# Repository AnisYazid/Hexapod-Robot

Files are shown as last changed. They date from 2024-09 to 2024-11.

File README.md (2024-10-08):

# Hexapod Robot with ESP32 and Jetson Nano

<div align="center">

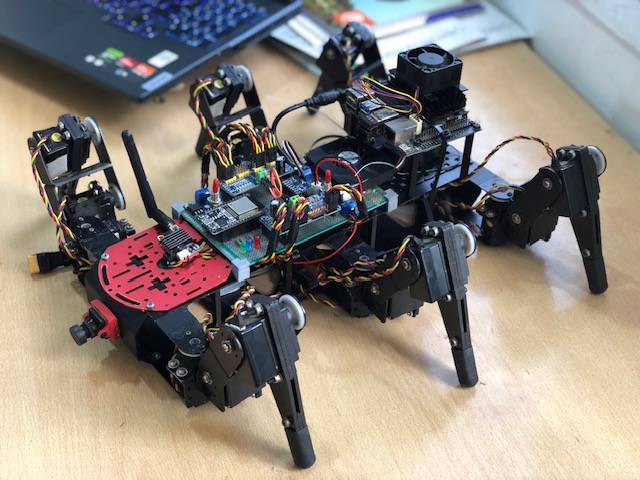
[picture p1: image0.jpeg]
Hexapod Robot
 
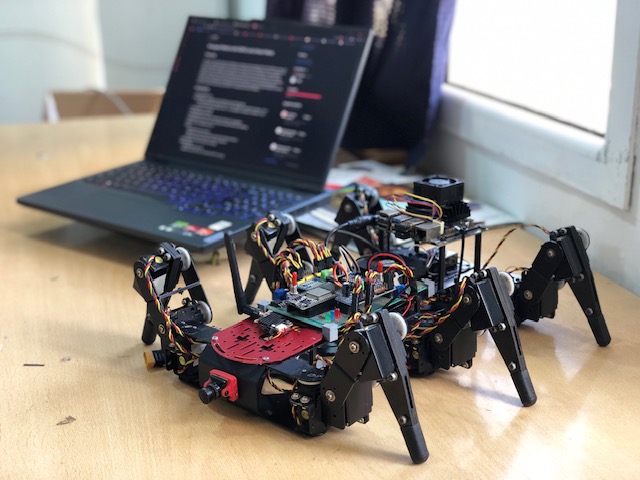
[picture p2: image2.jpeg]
HExapod Robot
 
 
</div>

## Overview
This project involves the design and development of a hexapod robot equipped with 18 HS-475HB servo motors for movement, controlled by an ESP32 microcontroller. The robot utilizes two PCA9685 servo drivers to manage the 18 servos—dividing them between the left and right sides for better control and coordination. An accelerometer is integrated for real-time calibration and stabilization. For movement, the robot employs Algebric Equations for smooth trajectory planning and PID (Proportional-Integral-Derivative) control for precise servo positioning. For autonomous navigation, the robot leverages a Jetson Nano paired with an Xbox Kinect V1 Depth Camera for environmental mapping and obstacle avoidance. Additionally, the robot features a buzzer and LEDs for debugging and status indication. The robot can also be controlled remotely using a Radiolink AT10 transmitter and RD12DS receiver.

## Components
- **Microcontroller:** ESP32
- **Servo Drivers:** 2 x PCA9685 (one for the left side, one for the right side)
  - **Right PCA9685 Address Modification: 0x41 ** A0 pin soldered to change the I2C address ( E-D-F )
  - **Left  PCA9685 Address Modification: 0x42 ** A1 pin soldered to change the I2C address ( A-B-C )
- **Servo Motors:** 18 x HS-475HB
- **Orientation Sensor:** MPU6050 
- **Processing Unit:** Jetson Nano (for advanced processing and AI capabilities)
- **Depth Sensor:** Xbox Kinect V1 (for 3D mapping and object detection amd mapping)
- **Buzzer:** For audio feedback and alerts
- **LEDs:**
  - **Red LED:** Main power indicator
  - **Blue LED:** Connection status indicator (searching for remote and Jetson)
  - **Green LED:** Setup ready indicator (all systems operational)
- **Power Supply:** 12V 30A power Supply 
- **Remote Control:**
  - **Transmitter:** Radiolink AT10II
  - **Receiver:** Radiolink RD12DS (connected to ESP32 via TX2 pin)

## Servo Motor Specification: HS-475HB
- **Modulation:** Analog
- **Torque:**
  - 4.8V: 61.0 oz-in (4.39 kg-cm)
  - 6.0V: 76.0 oz-in (5.47 kg-cm)
- **Speed:**
  - 4.8V: 0.23 sec/60°
  - 6.0V: 0.18 sec/60°
- **Weight:** 1.41 oz (40.0 g)
- **Dimensions:**
  - Length: 1.52 in (38.6 mm)
  - Width: 0.77 in (19.6 mm)
  - Height: 1.41 in (35.8 mm)
- **Motor Type:** 3-pole
- **Gear Type:** Plastic
- **Rotation/Support:** Single Bearing
- **Rotational Range:** 200°
- **Pulse Cycle:** 20 ms
- **Pulse Width:** 900-2100 µs

## Features
- **Dual PCA9685 Control:** Two PCA9685 drivers allow for precise control of 18 HS-475HB servos, with separate management for the left and right sides of the hexapod.

- **Smooth Movement:** Utilizes Bézier curves to generate smooth trajectories for the hexapod's movements, enhancing agility and fluidity.

- **PID Control:** Implements PID control for precise servo positioning, allowing for accurate and stable movement adjustments.
  
- **Real-Time Calibration:** Uses MPU6050 for detecting orientation and adjusting the robot's posture on-the-fly.
  
- **Autonomous Navigation:** Implements SLAM (Simultaneous Localization and Mapping) algorithms for navigating complex environments.
  
- **Obstacle Detection:** Utilizes Kinect V1 for depth perception and real-time obstacle avoidance.
  
- **Debugging Tools:** Buzzer for alerts and LEDs for indicating status (e.g., errors, operational states).
  
- **Remote Control Mode:** Allows manual operation via Radiolink AT10 transmitter.

## Installation
### Prerequisites
- **Hardware:**

  - ESP32 development board
  - 2 x PCA9685 servo drivers
  - 18 x HS-475HB servo motors
  - MPU6050 sensor
  - Jetson Nano
  - Kinect V2 sensor
  - Buzzer
  - LEDs:
    - Red for power
    - Blue for connection status
    - Green for setup readiness
  - Resistors for LEDs (if needed)
  - Radiolink AT10 transmitter
  - Radiolink RD12DS receiver
  - Power supply 12V 30A 
 
- **Software:**

   ```bash
   git clone https://github.com/yourusername/hexapod-robot.git
   cd hexapod-robot
   
### Install ESP32 Libraries
1. Open the Arduino IDE.
2. Go to **Sketch > Include Library > Manage Libraries**.
3. Search for and install:
   - Adafruit PWM Servo Driver Library
   - MPU6050 library
   - PID library (if necessary for your implementation)

### Install Jetson Nano Libraries
1. Open a terminal and install OpenCV:
   ```bash
   sudo apt-get install python3-opencv
   
2. Install ROS (Robot Operating System) following: [official ROS installation instructions](http://wiki.ros.org/ROS/Installation).
   
## Pinout

### ESP32 Connections
- **PCA9685 Servo Driver 1:**
  - SDA: GPIO 21
  - SCL: GPIO 22
  - **Servos:**
    - Servo A1: Channel 2
    - Servo A2: Channel 1
    - Servo A3: Channel 0
    - Servo B1: Channel 6
    - Servo B2: Channel 5
    - Servo B3: Channel 4
    - Servo C1: Channel 15
    - Servo C2: Channel 14
    - Servo C3: Channel 13

- **PCA9685 Servo Driver 2:**
  - SDA: GPIO 21
  - SCL: GPIO 22
  - **Servos:**
    - Servo D1: Channel 15
    - Servo D2: Channel 14
    - Servo D3: Channel 13
    - Servo E1: Channel 6
    - Servo E2: Channel 5
    - Servo E3: Channel 4
    - Servo F1: Channel 2
    - Servo F2: Channel 1
    - Servo F3: Channel 0
- **MPU6050:**
  - SDA: GPIO 21
  - SCL: GPIO 22
  - (Note: The MPU6050 also shares the same I2C pins)

- **LEDs:**
  - Red LED: GPIO 25
  - Blue LED: GPIO 4
  - Green LED: GPIO 2

- **Buzzer:**
  - Buzzer: GPIO 26
 
## Troubleshooting
### Common Issues

#### Servo Not Responding:
- Check the power supply to ensure the servos are receiving adequate voltage.
- Verify the wiring connections to the PCA9685 and ESP32.
- Ensure the correct I2C address is being used in the code.
- Inspect the servo motors for physical damage or mechanical binding.
- Test individual servos to confirm they are operational by connecting them directly to a power source.

#### Inconsistent Movement:
- Make sure the PID parameters are properly tuned for the specific movement requirements.
- Check the calibration of the MPU6050 to ensure accurate orientation readings.
- Monitor the servo feedback to ensure they are reaching the desired positions.
- Adjust the movement commands to ensure they are not exceeding the servo's capabilities.

#### LEDs Not Lighting Up:
- Confirm that the LEDs are wired correctly and that the appropriate pins are defined in the code.
- Check for any potential shorts or incorrect resistor values.
- Verify that the code includes logic to turn on the LEDs in the correct conditions.
- Test the LEDs individually to ensure they are functional.

#### Battery Issues:
- Monitor battery levels to ensure adequate power for all components.
- Check the battery connections for any loose or corroded terminals.
- Consider using a battery management system to prevent over-discharge and optimize performance.

## Future Work
  - **Advanced Sensor Integration:** Explore additional algorithms for obstacle avoidance and pathfinding
  
  - **Machine Learning:** Implement machine learning techniques for better decision-making and adaptive behaviors based on the robot's experiences.
    
  - **Battery Management System:** Develop a battery management system to monitor battery levels and optimize power consumption during operation.

## References
- **PCA9685 Library:** [Adafruit PWM Servo Driver Library](https://github.com/adafruit/Adafruit-PWM-Servo-Driver-Library)
  
- **MPU6050 Library:** [MPU6050 Library for Arduino](https://github.com/jrowberg/i2cdevlib/tree/master/Arduino/MPU6050)
  
- **PID Control:** [PID Controller Basics](https://en.wikipedia.org/wiki/PID_controller)
  
- **Bézier Curves:** [Understanding Bézier Curves](https://en.wikipedia.org/wiki/B%C3%A9zier_curve)

- **Easing Function Library:** [smooth movement for Servo](https://github.com/ArminJo/ServoEasing/tree/master)

- **NVIDIA Jetson Nano Installation:** [Jetson Nano Setup Guide](https://developer.nvidia.com/embedded/learn/get-started-jetson-nano-devkit)

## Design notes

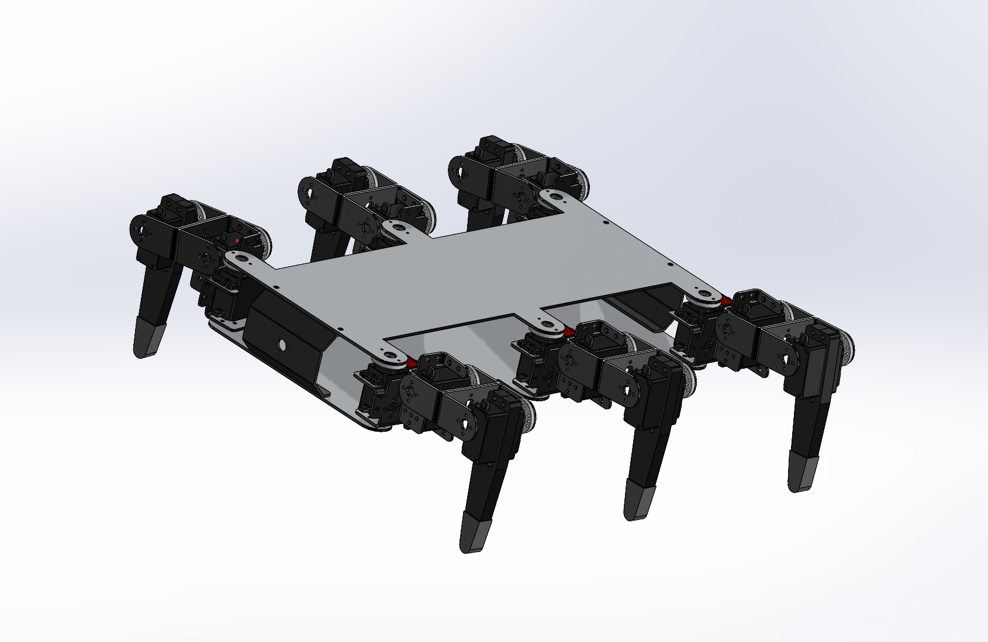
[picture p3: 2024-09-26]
3D model/Capture d'écran 2024-09-23 082227.png

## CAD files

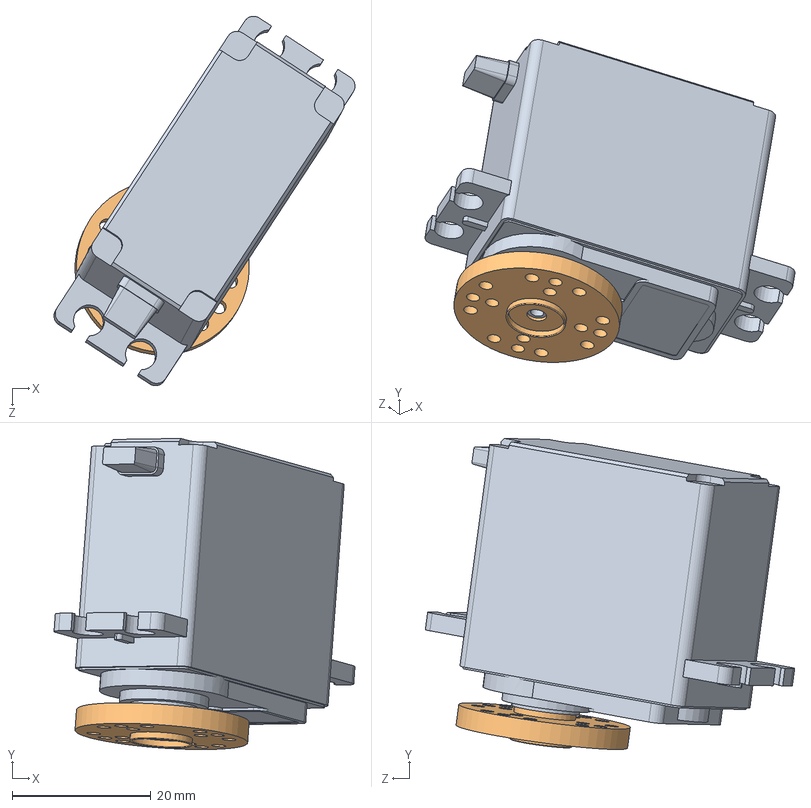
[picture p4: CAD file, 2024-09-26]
3D model/Servo.SLDASM
43.4 x 44.9 x 53.3 mm
Servo Hitec HS-475HB
Servo_Circle

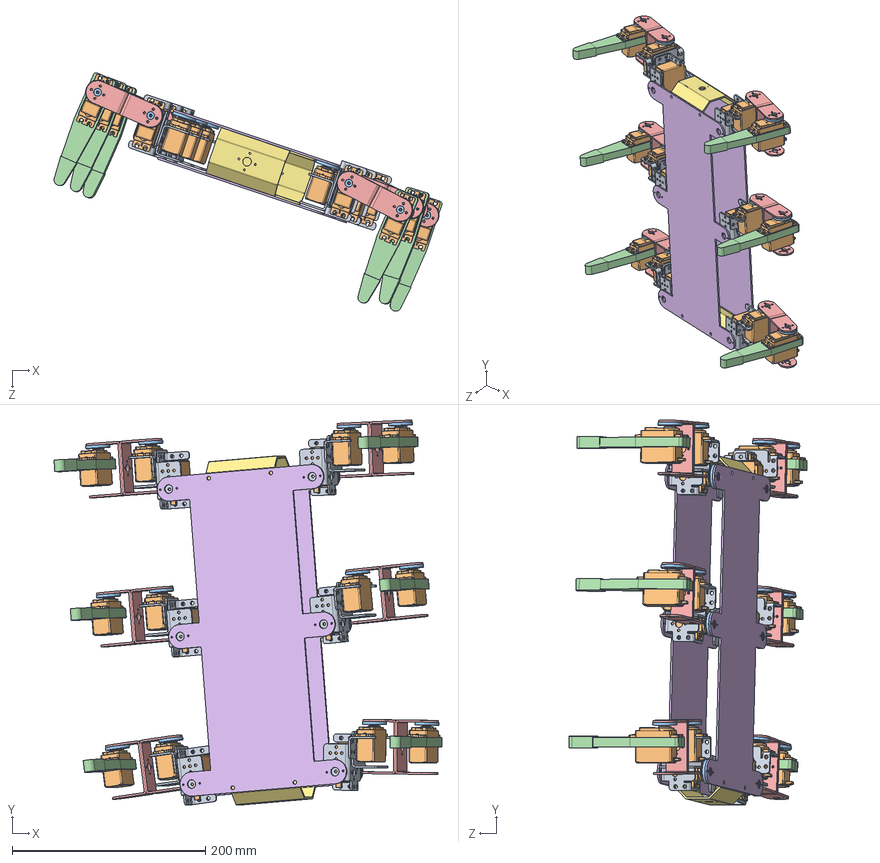
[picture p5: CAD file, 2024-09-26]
3D model/HEXA.SLDASM
401.1 x 397.8 x 246.5 mm
Servo Bracket - U Shaped_Défaut.step x 12
Servo Hitec HS-475HB x 18
Servo_Circle x 18
Leg_Tip x 6
U Bracket x 12
Base x 2
Front_Back_Spider x 2

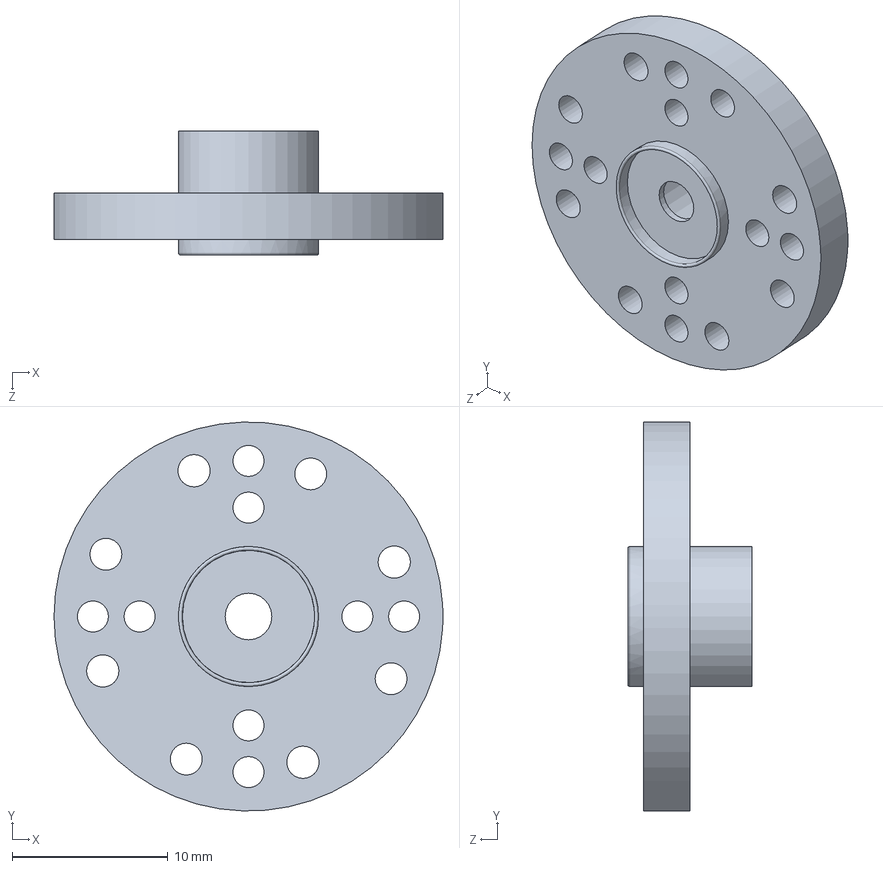
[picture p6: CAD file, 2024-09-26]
3D model/Servo_Circle.SLDPRT
25.0 x 25.0 x 8.00 mm

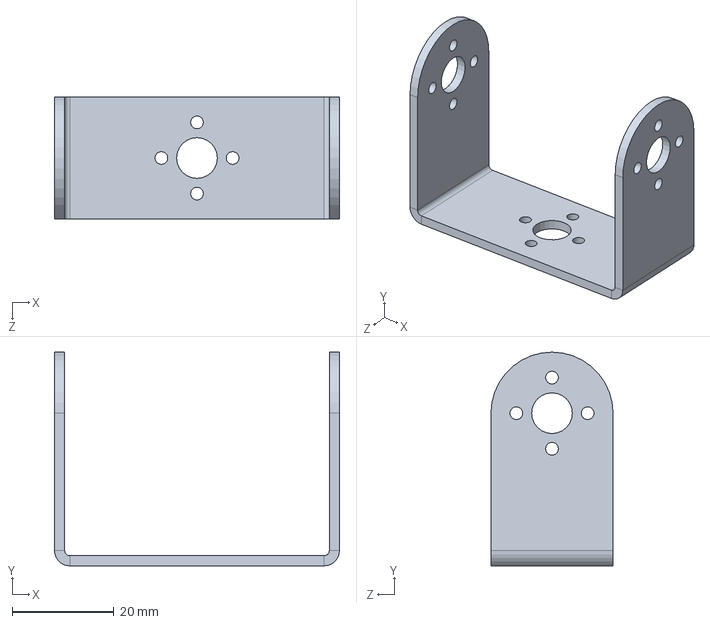
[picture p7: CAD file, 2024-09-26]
3D model/U Bracket.SLDPRT
56.0 x 42.0 x 24.0 mm

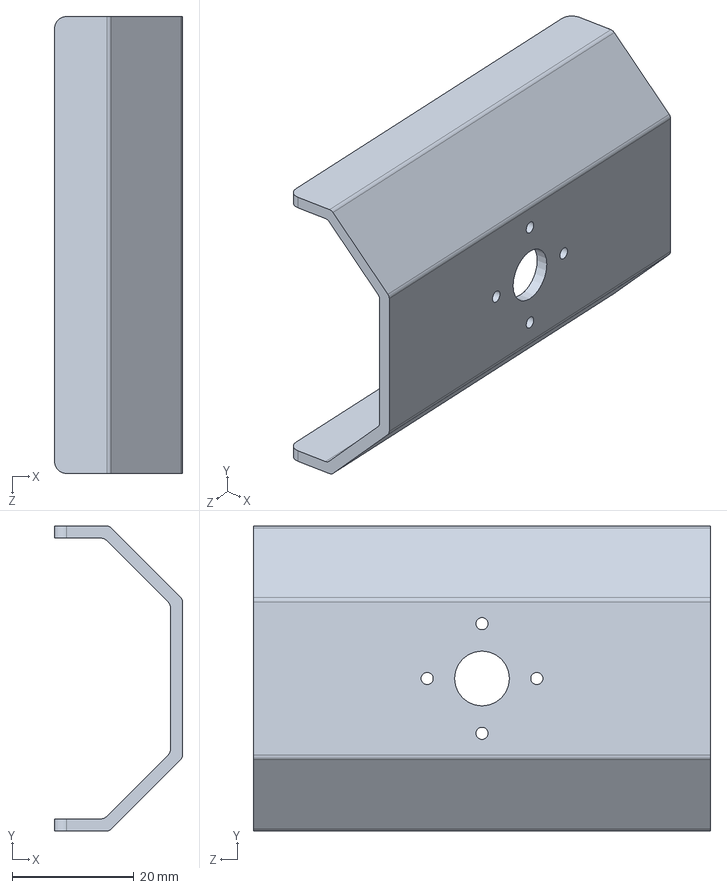
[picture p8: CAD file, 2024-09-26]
3D model/Front_Back_Spider.SLDPRT
21.0 x 50.0 x 75.0 mm

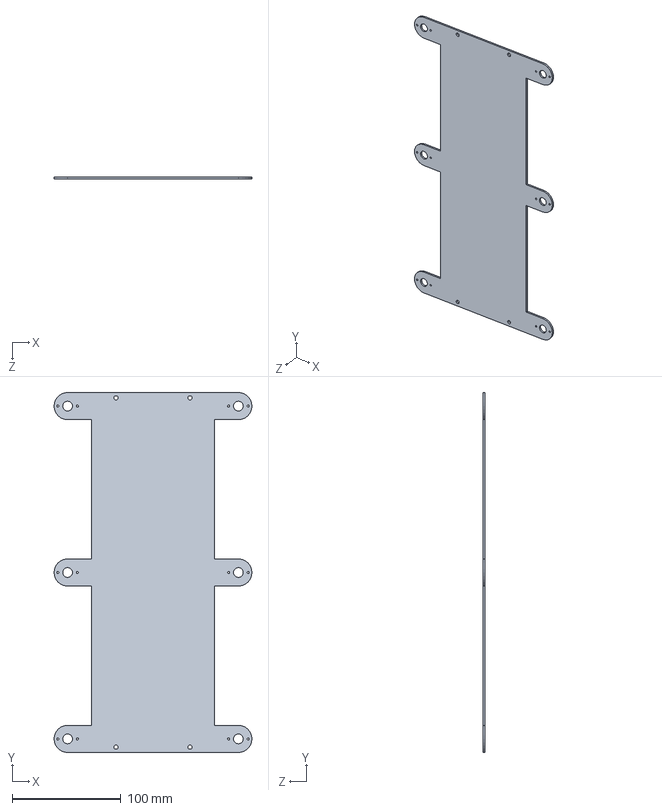
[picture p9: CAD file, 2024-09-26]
3D model/Base.SLDPRT
182.0 x 331.0 x 2.00 mm

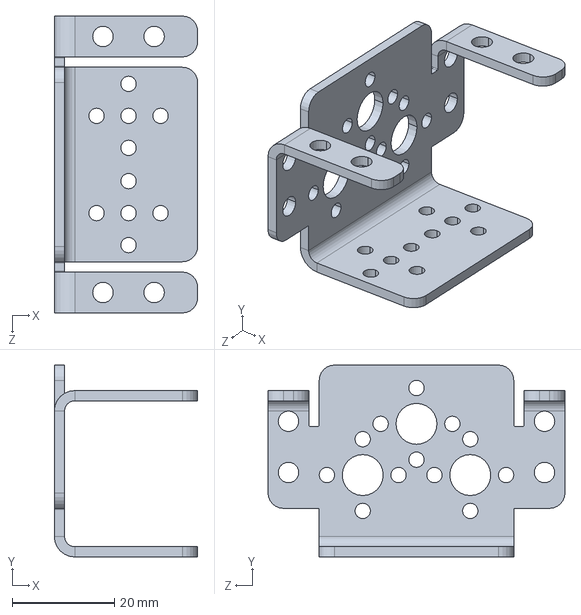
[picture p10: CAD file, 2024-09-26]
3D model/Servo Bracket - U Shaped_Défaut.step.SLDPRT
28.0 x 37.5 x 58.0 mm

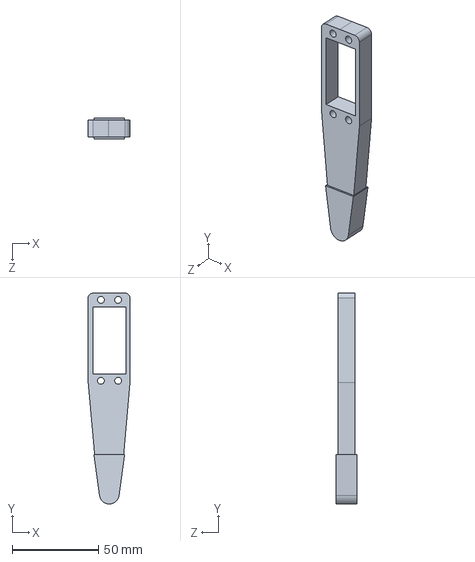
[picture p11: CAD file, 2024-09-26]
3D model/Leg_Tip.SLDPRT
24.4 x 122.6 x 12.0 mm

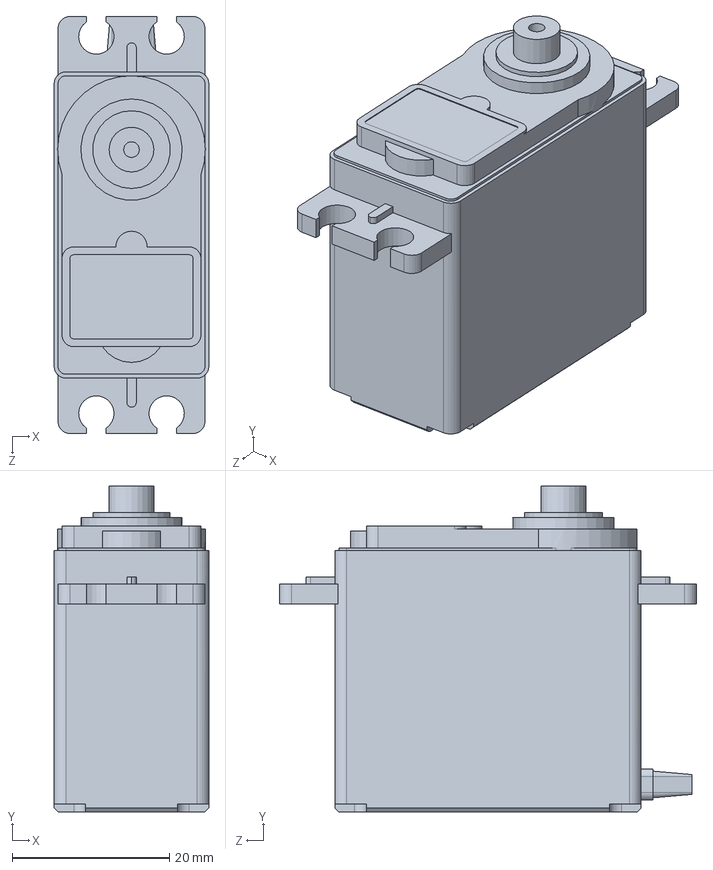
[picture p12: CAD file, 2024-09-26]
3D model/Servo Hitec HS-475HB.SLDPRT
19.7 x 41.5 x 53.1 mm

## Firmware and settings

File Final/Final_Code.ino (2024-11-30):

#include "sbus.h" // Include the SBUS library

using bfs::SbusRx;    // Bring SbusRx into the current scope
using bfs::SbusData;  // Bring SbusData into the current scope

// Define your RX and TX pins
const int8_t RX_PIN = 15; // Replace with your actual RX pin


/* SBUS object for reading SBUS */
SbusRx sbus_rx(&Serial2, RX_PIN,-1, true, false); // Adjust the last two bools as needed
/* SBUS object for writing SBUS */
SbusData data;

//////////////////////////////////////////

#include "Wire.h"
#include <MPU6050_light.h>

MPU6050 mpu(Wire);

long timer = 0;

//////////////////////////////////////////

#include <Wire.h>
#include <Adafruit_PWMServoDriver.h> // Include the PWM driver library

// Define addresses for the two PCA9685 modules
Adafruit_PWMServoDriver pwm_R = Adafruit_PWMServoDriver(0x41);
Adafruit_PWMServoDriver pwm_L = Adafruit_PWMServoDriver(0x42);

// Define pulse values for each servo

// Module 1 Servos/////////////////////////////////////////////////////////////////////

#define SERVO1_A1_MIN_PULSE 600 // Minimum pulse width for Servo 1 on Module 1
#define SERVO1_A1_MAX_PULSE 2600 // Maximum pulse width for Servo 1 on Module 1

#define SERVO1_A2_MIN_PULSE 600 // Minimum pulse width for Servo 2 on Module 1
#define SERVO1_A2_MAX_PULSE 2600 // Maximum pulse width for Servo 2 on Module 1

#define SERVO1_A3_MIN_PULSE 600 // Minimum pulse width for Servo 3 on Module 1
#define SERVO1_A3_MAX_PULSE 2600 // Maximum pulse width for Servo 3 on Module 1

#define SERVO1_B1_MIN_PULSE 600 // Minimum pulse width for Servo 4 on Module 1
#define SERVO1_B1_MAX_PULSE 2600 // Maximum pulse width for Servo 4 on Module 1

#define SERVO1_B2_MIN_PULSE 600 // Minimum pulse width for Servo 5 on Module 1
#define SERVO1_B2_MAX_PULSE 2600 // Maximum pulse width for Servo 5 on Module 1

#define SERVO1_B3_MIN_PULSE 600 // Minimum pulse width for Servo 6 on Module 1
#define SERVO1_B3_MAX_PULSE 2500 // Maximum pulse width for Servo 6 on Module 1

#define SERVO1_C1_MIN_PULSE 600 // Minimum pulse width for Servo 7 on Module 1
#define SERVO1_C1_MAX_PULSE 2600 // Maximum pulse width for Servo 7 on Module 1

#define SERVO1_C2_MIN_PULSE 500 // Minimum pulse width for Servo 8 on Module 1
#define SERVO1_C2_MAX_PULSE 2600 // Maximum pulse width for Servo 8 on Module 1

#define SERVO1_C3_MIN_PULSE 800 // Minimum pulse width for Servo 9 on Module 1
#define SERVO1_C3_MAX_PULSE 2700 // Maximum pulse width for Servo 9 on Module 1

// Module 2 Servos //////////////////////////////////////////////////////////////////////////

#define SERVO2_D1_MIN_PULSE 500 // Minimum pulse width for Servo 1 on Module 2
#define SERVO2_D1_MAX_PULSE 2500 // Maximum pulse width for Servo 1 on Module 2

#define SERVO2_D2_MIN_PULSE 700 // Minimum pulse width for Servo 2 on Module 2
#define SERVO2_D2_MAX_PULSE 2600 // Maximum pulse width for Servo 2 on Module 2

#define SERVO2_D3_MIN_PULSE 800 // Minimum pulse width for Servo 3 on Module 2
#define SERVO2_D3_MAX_PULSE 2700 // Maximum pulse width for Servo 3 on Module 2

#define SERVO2_E1_MIN_PULSE 600 // Minimum pulse width for Servo 4 on Module 2
#define SERVO2_E1_MAX_PULSE 2600 // Maximum pulse width for Servo 4 on Module 2

#define SERVO2_E2_MIN_PULSE 500 // Minimum pulse width for Servo 5 on Module 2
#define SERVO2_E2_MAX_PULSE 2600 // Maximum pulse width for Servo 5 on Module 2

#define SERVO2_E3_MIN_PULSE 600 // Minimum pulse width for Servo 6 on Module 2
#define SERVO2_E3_MAX_PULSE 2600 // Maximum pulse width for Servo 6 on Module 2

#define SERVO2_F1_MIN_PULSE 600 // Minimum pulse width for Servo 7 on Module 2
#define SERVO2_F1_MAX_PULSE 2600 // Maximum pulse width for Servo 7 on Module 2

#define SERVO2_F2_MIN_PULSE 500 // Minimum pulse width for Servo 8 on Module 2
#define SERVO2_F2_MAX_PULSE 2700 // Maximum pulse width for Servo 8 on Module 2

#define SERVO2_F3_MIN_PULSE 600 // Minimum pulse width for Servo 9 on Module 2
#define SERVO2_F3_MAX_PULSE 2600 // Maximum pulse width for Servo 9 on Module 2

////////////////////////////////

const int ledPinB = 45;
const int ledPinR = 21;
const int ledPinG = 47;


void setup()
{
    Serial.begin(115200);    /* Serial to display data */

    pwm_R.begin();
    pwm_R.setPWMFreq(50); // Set frequency to 50 Hz for servos

    pwm_L.begin();
    pwm_L.setPWMFreq(50); // Set frequency to 50 Hz for servos

      /* Begin the SBUS communication */
    sbus_rx.Begin(); // Initialize SBUS receiver


    Wire.begin();
    byte status = mpu.begin();
    mpu.calcOffsets(true, true);

    pinMode(ledPinB, OUTPUT);
    pinMode(ledPinR, OUTPUT);
    pinMode(ledPinG, OUTPUT);
    pinMode(20, OUTPUT); 
   
    digitalWrite(ledPinB, LOW);
    digitalWrite(ledPinR, HIGH);
    digitalWrite(ledPinG, LOW);

    tone (20, 600); 
    delay(200);
    tone (20, 1000);
    delay(200);
    noTone(20);
    delay(3000);
}

//////////////////////////////////////////////////////////

void loop ()
{
int f;
int a;
int i;
int j;
        
   
     if (sbus_rx.Read()) 
     {
        digitalWrite(ledPinB, HIGH);
        data = sbus_rx.data(); // Retrieve the received SBUS data
/*
if(data.ch[4] <= 310)
{ 
   if(data.ch[2] >= 1690)
  {
      // forward();
  }
 else if(data.ch[2] <=310)
  {
       backward();
  }
 else if(data.ch[0] <=310)
  {
       //Rot_R();
  }
 else if(data.ch[0] >=1690)
  {
       //Rot_L();
  }   
 else if(data.ch[3] <=310)
  {
       //Right();
  }
 else if(data.ch[3] >=1690)
  {
       //Left();
  }  
}


else if (data.ch[4] >= 1690)
{
  kabrage();
  D_G();
         
   setServoPosition(pwm_L, 2, 90);      // A1
   setServoPosition(pwm_L, 6, 90);      // B1
   setServoPosition(pwm_L, 15, 90);     // C1
   setServoPosition(pwm_R, 15, 90);     // D1
   setServoPosition(pwm_R, 6, 90);      // E1
   setServoPosition(pwm_R, 2, 90);      // F1
  
}

*/
        
      if (data.ch[4] <= 310) // value to check and Channel  
        {
              digitalWrite(ledPinG, HIGH);
              home();  
        }
        else if (data.ch[4] >= 1690) 
        {
              digitalWrite(ledPinG, HIGH);         
              stand();
        }
        else if (data.ch[8] <= 310)
        {
          digitalWrite(ledPinG,HIGH);
          UP_DW();
        }
         
        else if (data.ch[10] >= 1690)
        {
          digitalWrite(ledPinG,HIGH);
          kabrage();
          setServoPosition(pwm_L, 2, 90);      // A1
          setServoPosition(pwm_L, 6, 90);      // B1
          setServoPosition(pwm_L, 15, 90);     // C1
          setServoPosition(pwm_R, 15, 90);     // D1
          setServoPosition(pwm_R, 6, 90);      // E1
          setServoPosition(pwm_R, 2, 90);     // F1
          
        } 
        
        else if (data.ch[10] <= 310)
        {
          digitalWrite(ledPinG,HIGH);
          D_G();
         
          setServoPosition(pwm_L, 2, 90);      // A1
          setServoPosition(pwm_L, 6, 90);      // B1
          setServoPosition(pwm_L, 15, 90);     // C1
          setServoPosition(pwm_R, 15, 90);     // D1
          setServoPosition(pwm_R, 6, 90);      // E1
          setServoPosition(pwm_R, 2, 90);     // F1
        }  

        else if (data.ch[7] <= 310)
        {
          if(data.ch[5] <= 306)
          {
            digitalWrite(ledPinG, HIGH);
            forward() ;
          }
          else if(data.ch[5] >= 1690)
          {
            digitalWrite(ledPinG, HIGH);
            backward();
          }
        }
        else if (data.ch[7] >= 1690)
        {
            digitalWrite(ledPinG, HIGH);
            //  Rot();
            Fb();
        }


        

     } 
     
 


     
}
     


////////////////////////////////////////////////////////////

void setServoPosition(Adafruit_PWMServoDriver &pwm, int channel, int angle) 
{
    int pulseWidth;

    // Determine pulseWidth based on the angle
    switch (channel) 
    {
        case 0: // A1
            pulseWidth = map(angle, 0, 180, SERVO1_A1_MIN_PULSE, SERVO1_A1_MAX_PULSE);
            break;
        case 1: // A2
            pulseWidth = map(angle, 0, 180, SERVO1_A2_MIN_PULSE, SERVO1_A2_MAX_PULSE);
            break;
        case 2: // A3
            pulseWidth = map(angle, 0, 180, SERVO1_A3_MIN_PULSE, SERVO1_A3_MAX_PULSE);
            break;
        case 3: // B1
            pulseWidth = map(angle, 0, 180, SERVO1_B1_MIN_PULSE, SERVO1_B1_MAX_PULSE);
            break;
        case 4: // B2
            pulseWidth = map(angle, 0, 180, SERVO1_B2_MIN_PULSE, SERVO1_B2_MAX_PULSE);
            break;
        case 5: // B3
            pulseWidth = map(angle, 0, 180, SERVO1_B3_MIN_PULSE, SERVO1_B3_MAX_PULSE);
            break;
        case 6: // C1
            pulseWidth = map(angle, 0, 180, SERVO1_C1_MIN_PULSE, SERVO1_C1_MAX_PULSE);
            break;
        case 7: // C2
            pulseWidth = map(angle, 0, 180, SERVO1_C2_MIN_PULSE, SERVO1_C2_MAX_PULSE);
            break;
        case 8: // C3
            pulseWidth = map(angle, 0, 180, SERVO1_C3_MIN_PULSE, SERVO1_C3_MAX_PULSE);
            break;
        case 9: // D1
            pulseWidth = map(angle, 0, 180, SERVO2_D1_MIN_PULSE, SERVO2_D1_MAX_PULSE);
            break;
        case 10: // D2
            pulseWidth = map(angle, 0, 180, SERVO2_D2_MIN_PULSE, SERVO2_D2_MAX_PULSE);
            break;
        case 11: // D3
            pulseWidth = map(angle, 0, 180, SERVO2_D3_MIN_PULSE, SERVO2_D3_MAX_PULSE);
            break;
        case 12: // E1
            pulseWidth = map(angle, 0, 180, SERVO2_E1_MIN_PULSE, SERVO2_E1_MAX_PULSE);
            break;
        case 13: // E2
            pulseWidth = map(angle, 0, 180, SERVO2_E2_MIN_PULSE, SERVO2_E2_MAX_PULSE);
            break;
        case 14: // E3
            pulseWidth = map(angle, 0, 180, SERVO2_E3_MIN_PULSE, SERVO2_E3_MAX_PULSE);
            break;
        case 15: // F1
            pulseWidth = map(angle, 0, 180, SERVO2_F1_MIN_PULSE, SERVO2_F1_MAX_PULSE);
            break;
        case 16: // F2
            pulseWidth = map(angle, 0, 180, SERVO2_F2_MIN_PULSE, SERVO2_F2_MAX_PULSE);
            break;
        case 17: // F3
            pulseWidth = map(angle, 0, 180, SERVO2_F3_MIN_PULSE, SERVO2_F3_MAX_PULSE);
            break;
        default:
            pulseWidth = SERVO1_A1_MIN_PULSE; // Default case if channel is not recognized
            break;
    }

    // Calculate the PWM value
    int pulseValue = int(float(pulseWidth) / 1000000 * 50 * 4096);
    
    // Set the PWM on the specified channel
    pwm.setPWM(channel, 0, pulseValue);
}

void stand() 
{  

   int f=50;

   
    setServoPosition(pwm_L, 2, 90);      // A1
    setServoPosition(pwm_L, 1, f);     // A2
    setServoPosition(pwm_L, 0, f);     // A3
    
    setServoPosition(pwm_L, 6, 90);      // B1
    setServoPosition(pwm_L, 5, f);     // B2
    setServoPosition(pwm_L, 4, f);     // B3
    
    setServoPosition(pwm_L, 15, 90);     // C1
    setServoPosition(pwm_L, 14, f);    // C2
    setServoPosition(pwm_L, 13, f);    // C3
   
    setServoPosition(pwm_R, 15, 90);     // D1
    setServoPosition(pwm_R, 14, f);     // D2
    setServoPosition(pwm_R, 13, f);     // D3
   
    setServoPosition(pwm_R, 6, 90);      // E1
    setServoPosition(pwm_R, 5, f);      // E2
    setServoPosition(pwm_R, 4, f);       // E3
   
    setServoPosition(pwm_R, 2, 90);     // F1
    setServoPosition(pwm_R, 1, f);      // F2
    setServoPosition(pwm_R, 0, f);       // F3
}

void home() 
{  

    int a= 130;
    
    setServoPosition(pwm_L, 2, 90);      // A1
    setServoPosition(pwm_L, 1, a);     // A2
    setServoPosition(pwm_L, 0, a);     // A3
    
    setServoPosition(pwm_L, 6, 90);      // B1
    setServoPosition(pwm_L, 5, a);     // B2
    setServoPosition(pwm_L, 4, a);     // B3
    
    setServoPosition(pwm_L, 15, 90);     // C1
    setServoPosition(pwm_L, 14, a);    // C2
    setServoPosition(pwm_L, 13, a);    // C3
   
    setServoPosition(pwm_R, 15, 90);     // D1
    setServoPosition(pwm_R, 14, a);     // D2
    setServoPosition(pwm_R, 13, a);     // D3
   
    setServoPosition(pwm_R, 6, 90);      // E1
    setServoPosition(pwm_R, 5, a);      // E2
    setServoPosition(pwm_R, 4, a);       // E3
   
    setServoPosition(pwm_R, 2, 90);     // F1
    setServoPosition(pwm_R, 1, a);      // F2
    setServoPosition(pwm_R, 0, a);       // F3
}

void forward() 
{
    int f;

    float t = map(data.ch[6], 306, 1694, 0, 50);
    
  
    for ( f=90; f<=130;f++)
 {
      setServoPosition(pwm_L, 1, f);     // A2
      setServoPosition(pwm_L, 0, f);     // A3
  
      setServoPosition(pwm_L, 14, f);    // C2
      setServoPosition(pwm_L, 13, f);    // C3
  
      setServoPosition(pwm_R, 5, f);      // E2
      setServoPosition(pwm_R, 4, f);       // E3


      setServoPosition(pwm_L, 5, 80);     // B2
      setServoPosition(pwm_L, 4,80);     // B3
          
      setServoPosition(pwm_R, 14, 80);     // D2
      setServoPosition(pwm_R, 13, 80);     // D3
    
      setServoPosition(pwm_R, 1, 80);      // F2
      setServoPosition(pwm_R, 0, 80);       // F3
     delay(t);
  
 }
  

     for ( int i= 100 , j=80; j<=100 , i>= 80; j++ ,i--)
    {
                   setServoPosition(pwm_L, 2, i);      // A1
                   setServoPosition(pwm_L, 15, i);     // C1
                   setServoPosition(pwm_R, 6, j);      // E1
                   
                   setServoPosition(pwm_L, 6, j);      // B1
                   setServoPosition(pwm_R, 15, i);     // D1
                   setServoPosition(pwm_R, 2, i);     // F1]
                   delay(t);
                 
    }


    for ( f=130; f>=90;f--)
 {
      setServoPosition(pwm_L, 1, f);     // A2
      setServoPosition(pwm_L, 0, f);     // A3
  
      setServoPosition(pwm_L, 14, f);    // C2
      setServoPosition(pwm_L, 13, f);    // C3
  
      setServoPosition(pwm_R, 5, f);      // E2
      setServoPosition(pwm_R, 4, f);       // E3


      setServoPosition(pwm_L, 5, 80);     // B2
      setServoPosition(pwm_L, 4,80);     // B3
          
      setServoPosition(pwm_R, 14, 80);     // D2
      setServoPosition(pwm_R, 13, 80);     // D3
    
      setServoPosition(pwm_R, 1, 80);      // F2
      setServoPosition(pwm_R, 0, 80);       // F3
     delay(t);

 }


 
    for ( f=90; f<=120;f++)
 {
      setServoPosition(pwm_L, 1, 80);     // A2
      setServoPosition(pwm_L, 0, 80);     // A3
  
      setServoPosition(pwm_L, 14, 80);    // C2
      setServoPosition(pwm_L, 13, 80);    // C3
  
      setServoPosition(pwm_R, 5, 80);      // E2
      setServoPosition(pwm_R, 4, 80);       // E3

      setServoPosition(pwm_L, 5, f);     // B2
      setServoPosition(pwm_L, 4,f);     // B3
          
      setServoPosition(pwm_R, 14, f);     // D2
      setServoPosition(pwm_R, 13, f);     // D3
    
      setServoPosition(pwm_R, 1, f);      // F2
      setServoPosition(pwm_R, 0, f);       // F3
      delay(t);
  
 }
   
      for ( int i= 80 , j=100; j>=80 , i<= 100; j-- ,i++)
    {
                   setServoPosition(pwm_L, 2, i);      // A1
                   setServoPosition(pwm_L, 15, i);     // C1
                   setServoPosition(pwm_R, 6, j);      // E1
                   
                   setServoPosition(pwm_L, 6, j);      // B1
                   setServoPosition(pwm_R, 15, i);     // D1
                   setServoPosition(pwm_R, 2, i);     // F1
                   delay(t);
    }

 for ( f=120; f>=90;f--)
 {
      setServoPosition(pwm_L, 1, 80);     // A2
      setServoPosition(pwm_L, 0, 80);     // A3

      setServoPosition(pwm_L, 14, 80);    // C2
      setServoPosition(pwm_L, 13, 80);    // C3
  
      setServoPosition(pwm_R, 5, 80);      // E2
      setServoPosition(pwm_R, 4, 80);       // E3
      

      setServoPosition(pwm_L, 5, f);     // B2
      setServoPosition(pwm_L, 4, f);     // B3
          
      setServoPosition(pwm_R, 14, f);     // D2
      setServoPosition(pwm_R, 13, f);     // D3
    
      setServoPosition(pwm_R, 1, f);      // F2
      setServoPosition(pwm_R, 0, f);       // F3
      delay(t);
  
 }
 
}

void backward() 
{
    int f;

    float t = map(data.ch[6], 306, 1694, 0, 50);
    
  
    for ( f=90; f<=130;f++)
 {
      setServoPosition(pwm_L, 1, f);     // A2
      setServoPosition(pwm_L, 0, f);     // A3
  
      setServoPosition(pwm_L, 14, f);    // C2
      setServoPosition(pwm_L, 13, f);    // C3
  
      setServoPosition(pwm_R, 5, f);      // E2
      setServoPosition(pwm_R, 4, f);       // E3


      setServoPosition(pwm_L, 5, 80);     // B2
      setServoPosition(pwm_L, 4,80);     // B3
          
      setServoPosition(pwm_R, 14, 80);     // D2
      setServoPosition(pwm_R, 13, 80);     // D3
    
      setServoPosition(pwm_R, 1, 80);      // F2
      setServoPosition(pwm_R, 0, 80);       // F3
       delay(t);
  
 }
  


     for ( int i= 100 , j=80; j<=100 , i>= 80; j++ ,i--)
    {
                   setServoPosition(pwm_L, 2, j);      // A1
                   setServoPosition(pwm_L, 15, j);     // C1
                   setServoPosition(pwm_R, 6, i);      // E1
                   
                   setServoPosition(pwm_L, 6, i);      // B1
                   setServoPosition(pwm_R, 15, j);     // D1
                   setServoPosition(pwm_R, 2, j);     // F1]
               delay(t);      
    }

    for ( f=130; f>=90;f--)
 {
      setServoPosition(pwm_L, 1, f);     // A2
      setServoPosition(pwm_L, 0, f);     // A3
  
      setServoPosition(pwm_L, 14, f);    // C2
      setServoPosition(pwm_L, 13, f);    // C3
  
      setServoPosition(pwm_R, 5, f);      // E2
      setServoPosition(pwm_R, 4, f);       // E3


      setServoPosition(pwm_L, 5, 80);     // B2
      setServoPosition(pwm_L, 4,80);     // B3
          
      setServoPosition(pwm_R, 14, 80);     // D2
      setServoPosition(pwm_R, 13, 80);     // D3
    
      setServoPosition(pwm_R, 1, 80);      // F2
      setServoPosition(pwm_R, 0, 80);       // F3
     
    delay(t);
 }
  


  
    for ( f=90; f<=130;f++)
 {
      setServoPosition(pwm_L, 1, 80);     // A2
      setServoPosition(pwm_L, 0, 80);     // A3
  
      setServoPosition(pwm_L, 14, 80);    // C2
      setServoPosition(pwm_L, 13, 80);    // C3
  
      setServoPosition(pwm_R, 5, 80);      // E2
      setServoPosition(pwm_R, 4, 80);       // E3

      setServoPosition(pwm_L, 5, f);     // B2
      setServoPosition(pwm_L, 4,f);     // B3
          
      setServoPosition(pwm_R, 14, f);     // D2
      setServoPosition(pwm_R, 13, f);     // D3
    
      setServoPosition(pwm_R, 1, f);      // F2
      setServoPosition(pwm_R, 0, f);       // F3
     
    delay(t);
 }


      for ( int i= 80 , j=100; j>=80 , i<= 100; j-- ,i++)
    {
                   setServoPosition(pwm_L, 2, j);      // A1
                   setServoPosition(pwm_L, 15, j);     // C1
                   setServoPosition(pwm_R, 6, i);      // E1
                   
                   setServoPosition(pwm_L, 6, i);      // B1
                   setServoPosition(pwm_R, 15, j);     // D1
                   setServoPosition(pwm_R, 2, j);     // F1
                  delay(t);   
    }


 for ( f=120; f>=90;f--)
 {
      setServoPosition(pwm_L, 1, 80);     // A2
      setServoPosition(pwm_L, 0, 80);     // A3

      setServoPosition(pwm_L, 14, 80);    // C2
      setServoPosition(pwm_L, 13, 80);    // C3
  
      setServoPosition(pwm_R, 5, 80);      // E2
      setServoPosition(pwm_R, 4, 80);       // E3
      

      setServoPosition(pwm_L, 5, f);     // B2
      setServoPosition(pwm_L, 4, f);     // B3
          
      setServoPosition(pwm_R, 14, f);     // D2
      setServoPosition(pwm_R, 13, f);     // D3
    
      setServoPosition(pwm_R, 1, f);      // F2
      setServoPosition(pwm_R, 0, f);       // F3
      delay(t);
  
 }

}



void Rot()
{

     int r=90 ;
    float f = map(data.ch[3], 306, 1694, 120, 60);
    
  setServoPosition(pwm_L, 2, f);      // A1
    setServoPosition(pwm_L, 1, r);     // A2
    setServoPosition(pwm_L, 0, r);     // A3
    
    setServoPosition(pwm_L, 6, f);      // B1
    setServoPosition(pwm_L, 5, r);     // B2
    setServoPosition(pwm_L, 4, r);     // B3
    
    setServoPosition(pwm_L, 15, f);     // C1
    setServoPosition(pwm_L, 14, r);    // C2
    setServoPosition(pwm_L, 13, r);    // C3
   
    setServoPosition(pwm_R, 15, f);     // D1
    setServoPosition(pwm_R, 14, r);     // D2
    setServoPosition(pwm_R, 13, r);     // D3
   
    setServoPosition(pwm_R, 6, f);      // E1
    setServoPosition(pwm_R, 5, r);      // E2
    setServoPosition(pwm_R, 4, r);       // E3
   
    setServoPosition(pwm_R, 2, f);     // F1
    setServoPosition(pwm_R, 1, r);      // F2
    setServoPosition(pwm_R, 0, r);       // F3
}

void Fb()
{


    int r=90 ;
    float f = map(data.ch[2], 306, 1694, 120, 60);
    float a = map(data.ch[2], 306, 1694, 60, 120);
    
    setServoPosition(pwm_L, 2, f);      // A1
    setServoPosition(pwm_L, 1, r);     // A2
    setServoPosition(pwm_L, 0, r);     // A3
    
    setServoPosition(pwm_L, 6, f);      // B1
    setServoPosition(pwm_L, 5, r);     // B2
    setServoPosition(pwm_L, 4, r);     // B3
    
    setServoPosition(pwm_L, 15, f);     // C1
    setServoPosition(pwm_L, 14, r);    // C2
    setServoPosition(pwm_L, 13, r);    // C3
   
    setServoPosition(pwm_R, 15, a);     // D1
    setServoPosition(pwm_R, 14, r);     // D2
    setServoPosition(pwm_R, 13, r);     // D3
   
    setServoPosition(pwm_R, 6, a);      // E1
    setServoPosition(pwm_R, 5, r);      // E2
    setServoPosition(pwm_R, 4, r);       // E3
   
    setServoPosition(pwm_R, 2, a);     // F1
    setServoPosition(pwm_R, 1, r);      // F2
    setServoPosition(pwm_R, 0, r);       // F3
}
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

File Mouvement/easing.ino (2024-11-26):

#include <Wire.h>
#include <Adafruit_PWMServoDriver.h>


Adafruit_PWMServoDriver pwm_R = Adafruit_PWMServoDriver(0x41);
Adafruit_PWMServoDriver pwm_L = Adafruit_PWMServoDriver(0x42);

// Define pulse width limits for each servo (example values, adjust as needed)
#define SERVO1_A1_MIN_PULSE 600 
#define SERVO1_A1_MAX_PULSE 2600 
#define SERVO1_A2_MIN_PULSE 600 
#define SERVO1_A2_MAX_PULSE 2600 
#define SERVO1_A3_MIN_PULSE 600 
#define SERVO1_A3_MAX_PULSE 2600 
#define SERVO1_B1_MIN_PULSE 600 
#define SERVO1_B1_MAX_PULSE 2600 
#define SERVO1_B2_MIN_PULSE 600 
#define SERVO1_B2_MAX_PULSE 2600 
#define SERVO1_B3_MIN_PULSE 600 
#define SERVO1_B3_MAX_PULSE 2600 
#define SERVO1_C1_MIN_PULSE 600 
#define SERVO1_C1_MAX_PULSE 2600 
#define SERVO1_C2_MIN_PULSE 600 
#define SERVO1_C2_MAX_PULSE 2600 
#define SERVO1_C3_MIN_PULSE 600 
#define SERVO1_C3_MAX_PULSE 2600 
#define SERVO2_D1_MIN_PULSE 600 
#define SERVO2_D1_MAX_PULSE 2600 
#define SERVO2_D2_MIN_PULSE 600 
#define SERVO2_D2_MAX_PULSE 2600 
#define SERVO2_D3_MIN_PULSE 600 
#define SERVO2_D3_MAX_PULSE 2600 
#define SERVO2_E1_MIN_PULSE 600 
#define SERVO2_E1_MAX_PULSE 2600 
#define SERVO2_E2_MIN_PULSE 600 
#define SERVO2_E2_MAX_PULSE 2600 
#define SERVO2_E3_MIN_PULSE 600 
#define SERVO2_E3_MAX_PULSE 2600 
#define SERVO2_F1_MIN_PULSE 600 
#define SERVO2_F1_MAX_PULSE 2600 
#define SERVO2_F2_MIN_PULSE 600 
#define SERVO2_F2_MAX_PULSE 2600 
#define SERVO2_F3_MIN_PULSE 600 
#define SERVO2_F3_MAX_PULSE 2600 


float results[200];
float start = 50;       // Starting value
float endValue = 120;   // Ending value
float duration = 0.25;     // Duration in seconds
int frames = 150;       // Number of frames for the animation


void setup() 
{
    pwm_R.begin();
    pwm_R.setPWMFreq(50); // Set frequency to 50 Hz for servos
    pwm_L.begin();
    pwm_L.setPWMFreq(50); // Set frequency to 50 Hz for servos
 
  
}

void cubicInOutEasing(float start, float endValue, float duration, int frames) {
    float t_values[frames];
    for (int i = 0; i < frames; i++) {
        t_values[i] = (float)i / (frames - 1); // Normalized time from 0 to 1
    }
    for (int i = 0; i < frames; i++) {
        float t = t_values[i];
        if (t < 0.5) {
            results[i] = start + (endValue - start) * (4 * t * t * t); // Ease In
        } else {
            results[i] = start + (endValue - start) * (1 - ((-2 * t + 2) * (-2 * t + 2) * (-2 * t + 2)) / 2); // Ease Out
        }
    }
}

void setServoPosition(Adafruit_PWMServoDriver &pwm, int channel, int angle) {
    int pulseWidth;
    switch (channel) {
        case 0: pulseWidth = map(angle, 0, 180, SERVO1_A1_MIN_PULSE, SERVO1_A1_MAX_PULSE); break;
        case 1: pulseWidth = map(angle, 0, 180, SERVO1_A2_MIN_PULSE, SERVO1_A2_MAX_PULSE); break;
        case 2: pulseWidth = map(angle, 0, 180, SERVO1_A3_MIN_PULSE, SERVO1_A3_MAX_PULSE); break;
        case 3: pulseWidth = map(angle, 0, 180, SERVO1_B1_MIN_PULSE, SERVO1_B1_MAX_PULSE); break;
        case 4: pulseWidth = map(angle, 0, 180, SERVO1_B2_MIN_PULSE, SERVO1_B2_MAX_PULSE); break;
        case 5: pulseWidth = map(angle, 0, 180, SERVO1_B3_MIN_PULSE, SERVO1_B3_MAX_PULSE); break;
        case 6: pulseWidth = map(angle, 0, 180, SERVO1_C1_MIN_PULSE, SERVO1_C1_MAX_PULSE); break;
        case 7: pulseWidth = map(angle, 0, 180, SERVO1_C2_MIN_PULSE, SERVO1_C2_MAX_PULSE); break;
        case 8: pulseWidth = map(angle, 0, 180, SERVO1_C3_MIN_PULSE, SERVO1_C3_MAX_PULSE); break;
        case 9: pulseWidth = map(angle, 0, 180, SERVO2_D1_MIN_PULSE, SERVO2_D1_MAX_PULSE); break;
        case 10: pulseWidth = map(angle, 0, 180, SERVO2_D2_MIN_PULSE, SERVO2_D2_MAX_PULSE); break;
        case 11: pulseWidth = map(angle, 0, 180, SERVO2_D3_MIN_PULSE, SERVO2_D3_MAX_PULSE); break;
        case 12: pulseWidth = map(angle, 0, 180, SERVO2_E1_MIN_PULSE, SERVO2_E1_MAX_PULSE); break;
        case 13: pulseWidth = map(angle, 0, 180, SERVO2_E2_MIN_PULSE, SERVO2_E2_MAX_PULSE); break;
        case 14: pulseWidth = map(angle, 0, 180, SERVO2_E3_MIN_PULSE, SERVO2_E3_MAX_PULSE); break;
        case 15: pulseWidth = map(angle, 0, 180, SERVO2_F1_MIN_PULSE, SERVO2_F1_MAX_PULSE); break;
        case 16: pulseWidth = map(angle, 0, 180, SERVO2_F2_MIN_PULSE, SERVO2_F2_MAX_PULSE); break;
        case 17: pulseWidth = map(angle, 0, 180, SERVO2_F3_MIN_PULSE, SERVO2_F3_MAX_PULSE); break;
        default: pulseWidth = SERVO1_A1_MIN_PULSE; break; // Default case
    }
    int pulseValue = int(float(pulseWidth) / 1000000 * 50 * 4096);
    pwm.setPWM(channel, 0, pulseValue);
}

void UP_DW() 
{
 cubicInOutEasing(start, endValue, duration, frames);
  for (int i = 0; i < frames; i++) 
    {
    setServoPosition(pwm_L, 2, 90);      // A1
    setServoPosition(pwm_L, 1, results[i]);     // A2
    setServoPosition(pwm_L, 0, results[i]);     // A3
    
    setServoPosition(pwm_L, 6, 90);      // B1
    setServoPosition(pwm_L, 5, results[i]);     // B2
    setServoPosition(pwm_L, 4, results[i]);     // B3
    
    setServoPosition(pwm_L, 15, 90);     // C1
    setServoPosition(pwm_L, 14, results[i]);    // C2
    setServoPosition(pwm_L, 13, results[i]);    // C3
   
    setServoPosition(pwm_R, 15, 90);     // D1
    setServoPosition(pwm_R, 14, results[i]);     // D2
    setServoPosition(pwm_R, 13, results[i]);     // D3
   
    setServoPosition(pwm_R, 6, 90);      // E1
    setServoPosition(pwm_R, 5, results[i]);      // E2
    setServoPosition(pwm_R, 4, results[i]);       // E3
   
    setServoPosition(pwm_R, 2, 90);     // F1
    setServoPosition(pwm_R, 1, results[i]);      // F2
    setServoPosition(pwm_R, 0, results[i]);       // F3
        
        delay((duration * 1000) / frames); // Delay to match the frame rate
    }

    delay(2000);
    cubicInOutEasing(endValue, start, duration, frames);
      for (int i = 0; i < frames; i++) 
    {
    setServoPosition(pwm_L, 2, 90);      // A1
    setServoPosition(pwm_L, 1, results[i]);     // A2
    setServoPosition(pwm_L, 0, results[i]);     // A3
    
    setServoPosition(pwm_L, 6, 90);      // B1
    setServoPosition(pwm_L, 5, results[i]);     // B2
    setServoPosition(pwm_L, 4, results[i]);     // B3
    
    setServoPosition(pwm_L, 15, 90);     // C1
    setServoPosition(pwm_L, 14, results[i]);    // C2
    setServoPosition(pwm_L, 13, results[i]);    // C3
   
    setServoPosition(pwm_R, 15, 90);     // D1
    setServoPosition(pwm_R, 14, results[i]);     // D2
    setServoPosition(pwm_R, 13, results[i]);     // D3
   
    setServoPosition(pwm_R, 6, 90);      // E1
    setServoPosition(pwm_R, 5, results[i]);      // E2
    setServoPosition(pwm_R, 4, results[i]);       // E3
   
    setServoPosition(pwm_R, 2, 90);     // F1
    setServoPosition(pwm_R, 1, results[i]);      // F2
    setServoPosition(pwm_R, 0, results[i]);       // F3
        
        delay((duration * 1000) / frames); // Delay to match the frame rate
    }

    delay(2000);
}
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

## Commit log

2024-09-09 i added the accelerometer readings
2024-09-15 Added easing function
    implemented easeOoutCubic for smooth transitions
    updated the home() function
    added setServoPosition function to apply easing function for setting the 18 servo's positions
2024-09-15 correct some errors syntax
    [Home_Pos.ino]
2024-09-17 need calibration
2024-09-18 i added a servo calibration code
2024-09-26 mofify the pulse for all the servo
2024-10-03 update Gyro
2024-11-27 update for ESP32 S3
2024-11-30 update for the ESP32 S3
